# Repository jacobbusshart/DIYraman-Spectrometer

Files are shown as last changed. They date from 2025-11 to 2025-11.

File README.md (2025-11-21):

# DIYRaman – Open Hardware Raman Spectrometer 

An open, modular Raman spectrometer you can build, understand, and modify –  with documentation aimed at hobbyists, educators, and low-resource labs.

Full Assembly in Overpressure Glove Box without Cuvette

The goal is to make Raman spectroscopy **replicable, affordable, and well-documented**, so that motivated builders – including those without access to expensive equipment – can build a working system for:

- broad substance and drug identification *(qualitative, exploratory)*,
- basic materials identification,
- teaching optics and spectroscopy.

 Built from cost-efficient parts and repurposed components:
 
- a surplus spectrometer module [(B&W Tek - eBay](https://www.ebay.com/itm/143989529085)),
- a cheap 532nm laser pointer,
- 3D-printed parts,
- various used components.

For performance and reproducibility, essential optics had to be purchased new from Thorlabs and Edmund Optics – the most costly portion of this build:

- Dichroic Mirror (DMLP550 - Thorlabs, 230$)
- Longpass Filter (FELH0550 - Thorlabs, 170$)
- (Optional) Bandpass Filter (#65640 - Edmund Optics, 95$)

A detailed overview of all the used parts and cost can be found under `/bom/BOM (Bill of Materials).md`

This repository contains:

- **Build documentation** (step-by-step with images),
- **Hardware design files** (3D models and Fusion CAD files),
- **Software** for acquisition and visualisation,
- **BOMs** with parts, essential properties and alternatives.

> 💡 This README is a *project overview*. Detailed build instructions can be found in `docs/` and the dedicated pages (Basic Assembly, Glove Box, Linear Stage, Full Assembly, …).

---

## Who is this for?



DIYRaman is designed for:

- 🛠️ **Makers & hobbyists** with a 3D printer and basic electronics skills  
- 📚 **Teachers & students** who want a hands-on, explainable spectrometer  
- 🌍 **Low-resource labs** where commercial Raman devices are inaccessible  
- 💊 **Curious experimenters** exploring qualitative screening and comparison

You should be comfortable with:

- basic hand tools,
- 3d-printing,
- following technical step-by-step instructions,
- handling lasers safely - or receive guidance from someone.

> ⚠️ **Not a certified analytical instrument**  
> DIYRaman is a learning and research tool. It is **not validated** for clinical, regulatory, or forensic decisions and only yields broad qualitative results.

---

## What can it do?

The completed Raman build offers:

- **Stokes region** above ~600 cm⁻¹  
- solids / liquids in a cuvette-type sample holder  
- qualitative & educational use (comparison, teaching, demos)  
- extensible design (alternative spectrometers, lasers, mechanics)

> 🧪 **Drug / counterfeit screening**  
> The system can be used for *exploratory, educational* screening of unknowns (e.g. counterfeit pills) but **must not** be treated as a validated forensic tool. **Always cross-check with certified methods!**

---

## Project status

> **Early open release — Work in progress**

Hardware and docs are under active development. Conventions, part numbers, files, and instructions may change.

Current module status:

- ✅ **Basic Raman Optical Assembly** – documented and buildable  
- ✅ **Overpressure Glove Box** – documented and buildable  
- 🟡 **Linear Translation Stage** – documented, design still being adjusted  
- 🟡 **Spectrometer Unit** – usable, documentation in progress  
- 🟠 **Full Raman Optical Assembly** – documentation in progress  
- 🔴 **First Acquisition & Software / GUI** – unpublished  

Breaking changes may occur; expect adjustments until the first tagged release.

---

## Repository structure (WiP – early draft)

```text
assets/
  images_animated/
  images_infographic/
  images_picked/
  images_pictures/
  images_print-orientation/

bom/
  BOM.csv                 # Incomplete; updated in respective instruction!
  
docs/
  instructions/           # Step-by-step build docs

parts/                    # .STL-files for 3D-printing
  basic-assembly/
  glovebox/

results/                  # Captured example spectra

software/                 # Planned

LICENSES/
  CERN_OHL_S_V2.txt
  CC-BY-SA-4.0.txt
  MIT.txt
```

- Build *instructions* in `docs/instructions/`.  
- Hardware *source files* in `parts/`.
- All *images* and supporting graphics in `assets/`.
- Complete BOM in `bom/` and respective instruction.  
- License texts in `LICENSES/`.

---

## Build path (recommended)

A suggested build order for new users:

1. **Spectrometer Setup**  
   – Become comfortable with the operation of the spectrometer unit .  
2. **Overpressure Glove Box**  
   – Keep dust away from optics and make laser alignment safer.  
3. **Basic Raman Optical Assembly**  
   – Align the basic backscattering optical path.  
   - *Acquire your first rough spectrum.*  
3. **Linear Translation Stage**  
   – Add fine focus control for the focusing optics.  
4. **Full Raman Optical Assembly**  
   – Add motorisation, translation stage, and refinements.  
   - *Acquire your first usable Raman spectrum.*  
5. **Calibration** *(planned)*  
   – Calibrate wavelength axis and intensity where feasible.  
6. **Upgrade options** *(planned)*  
   – Alternative optics, higher-quality mechanics, software features.



---

## Contributing

Contributions are very welcome – especially from people building the system.

You can help by:

- reporting unclear or missing steps in the docs,  
- proposing improved or more accessible part choices,  
- designing mechanical variants (e.g. alternative mounts, stages),  
- improving the GUI / firmware,  
- sharing example spectra and calibration tips.

---

## Teaching & research use

If you use DIYRaman in teaching, workshops, or research:

- Consider contributing your **findings, documentation, worksheets, or demos** back to the project.  
- If you publish work based on DIYRaman, please cite it so others can find it.

Until the first proper release is published, you can use the following citation: 

> **DIYRaman - Open Hardware Raman Spectrometer (Github),**   
> *Jacob Busshart, DIYraman.com*

---

## Acknowledgements

This project builds on the shared knowledge and contributions of the open-hardware community. Some particularly helpful references and inspirations:

- [OpenRaman.org](https://www.open-raman.org/) & [ThePulsar.be](https://www.thepulsar.be/article/diy-raman-spectroscopy/) (Luc)  
- [PhysicsOpenLab.org – Backscattering Raman system](https://physicsopenlab.org/2022/04/22/backscattering-raman-system/)  
- [Laserpointerforums.com – B&W Tek spectrometer thread](https://laserpointerforums.com/threads/b-w-tech-spectrometer-473-module-setup-mods-info.101467/)

If you adapt or extend this design, please consider releasing your variant as open hardware too – especially if it makes the system easier to build in your local context.

---

## Licensing – open hardware setup

DIYRaman separates licenses for **hardware**, **documentation**, and **software**.  
This follows common open-hardware practice and simplifies reuse.

**Hardware**: 
All **hardware design files** in this repository (mechanical CAD, STLs, STEP files, electronics schematics and layouts) are licensed under:
**CERN-OHL-S v2**
`LICENSES/CERN_OHL_S_V2.txt` 

**Documentation**: 
All **build instructions, diagrams, and written documentation** in this repository are licensed under: 
**Creative Commons Attribution-ShareAlike 4.0 International (CC BY-SA 4.0)**
`LICENSES/CC-BY-SA-4.0.txt`

**Software**: 
All **software** in this repository (code and firmware) is licensed under:
**MIT License**
`LICENSES/MIT.txt`

---

*NOTE: Some parts of the written documentation has been formatted or translated using AI.*



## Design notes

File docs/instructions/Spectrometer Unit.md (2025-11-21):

# Spectrometer Unit (B&W Tek BTC-110S)

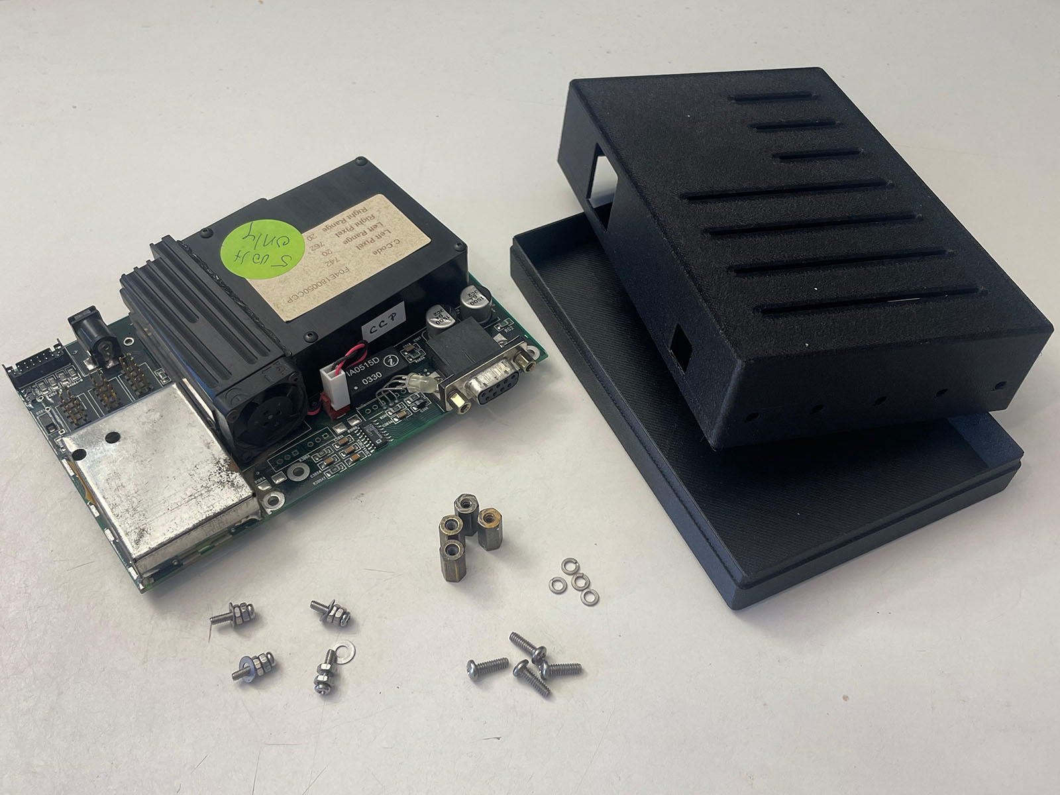
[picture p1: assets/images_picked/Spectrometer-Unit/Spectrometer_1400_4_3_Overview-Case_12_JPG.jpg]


This module describes how to prepare, house and use the [**B&W Tek BTC-110S**](https://www.ebay.com/itm/143989529085) spectrometer board as the detector for the DIYraman system.

It covers inspection and cleaning, the 3D-printed housing, first power-up, acquiring spectra, and basic wavelength calibration.

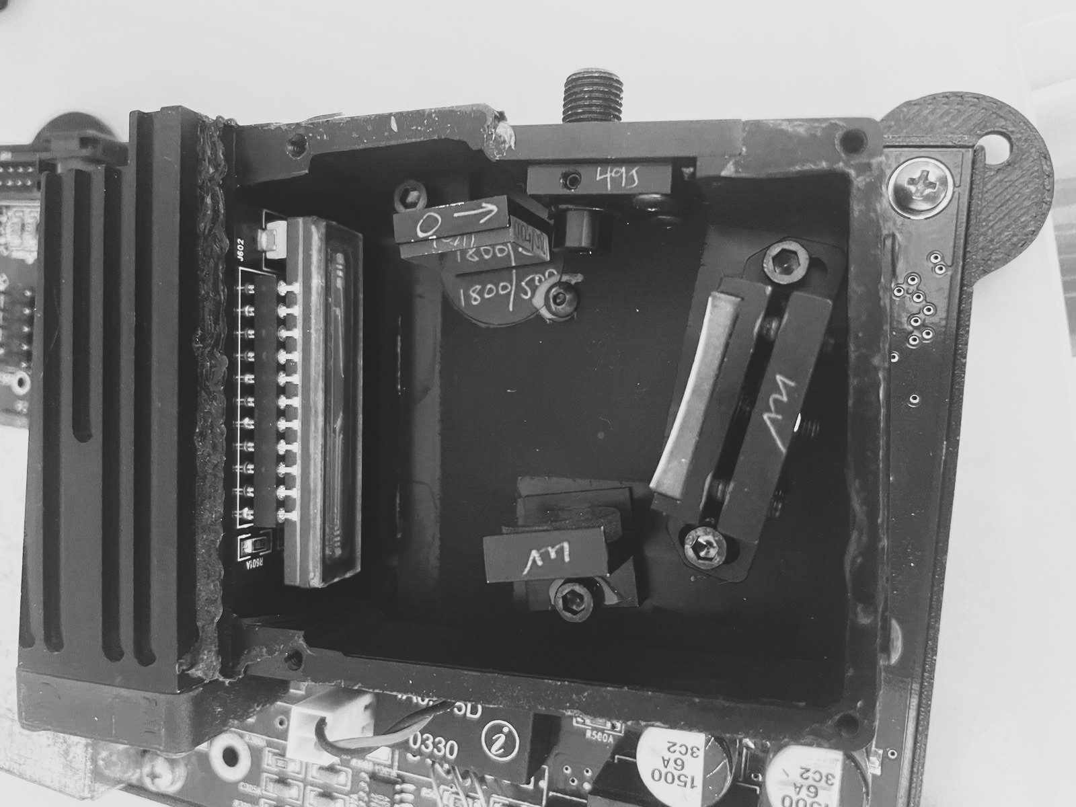
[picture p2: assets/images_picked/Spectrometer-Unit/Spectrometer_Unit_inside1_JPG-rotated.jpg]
View inside the optical assembly of the Spectrometer Unit BTC-110S


***For an in-depth look into the capabilities and operation of the unit, visit this blog post ["Home Optical Spectrometry: The B&W Tek BTC100-2S"](https://www.sevarg.net/2023/01/28/bw-tek-btc100-spectrometer/) on Sevarg.net!***

---

## Jump to

- [1. Parts and Tools](#1-parts-and-tools)
- [2. Inspect and Clean the Unit](#2-inspect-and-clean-the-unit)
- [3. 3D-Printed Housing](#3-3d-printed-housing)
- [4. Powering On and Connecting](#4-powering-on-and-connecting)
- [5. Acquiring a First Spectrum](#5-acquiring-a-first-spectrum)
- [6. Wavelength Calibration](#6-wavelength-calibration)
- [7. Upgrade Options (Optional)](#7-upgrade-options-optional)
- [Appendix – Background](#appendix--background)

---

## 1. Parts and Tools

### 1.1 Sourced parts

| Part | Minimum spec / example | Notes |
| --- | --- | --- |
| Spectrometer board | **B&W Tek BTC-110S** ([Available on eBay](https://www.ebay.com/itm/143989529085)) | Main detector module. |
| Power supply | 5 V, ≥ 3 A, barrel jack connector | Must be stable and regulated. |
| Data cable | RS-232 to USB adapter cable | Choose a chipset compatible with your OS (many FTDI / Prolific chips work reliably). |
| Calibration source | CFL or mercury-vapour / calibration lamp | Needs several sharp lines near ~550 nm for wavelength calibration. |

> [!TIP] Budget builds  
> Used BTC-110S boards are available on eBay but may also appear via surplus or auction sites and are much cheaper than new spectrometers or even buying the parts.

---

### 1.2 Tools

- Small **hand blower** (camera cleaning blower) or compressed inert gas  
- Lint-free cloth and **99 % isopropanol**  
- Cotton swabs  
- Basic screwdrivers and hex keys (for standoffs / case)  
- 3D printer capable of PETG or PETG-CF  
- PC or laptop with Windows and:
  - Original B&W Tek software (re-hosted)  
  - Optional: DIYraman acquisition software (see [Software – README](../../software/README.md))

---

## 2. Inspect and Clean the Unit

Before printing parts or powering anything, make sure your spectrometer arrived intact. 

### 2.1 Visual overview

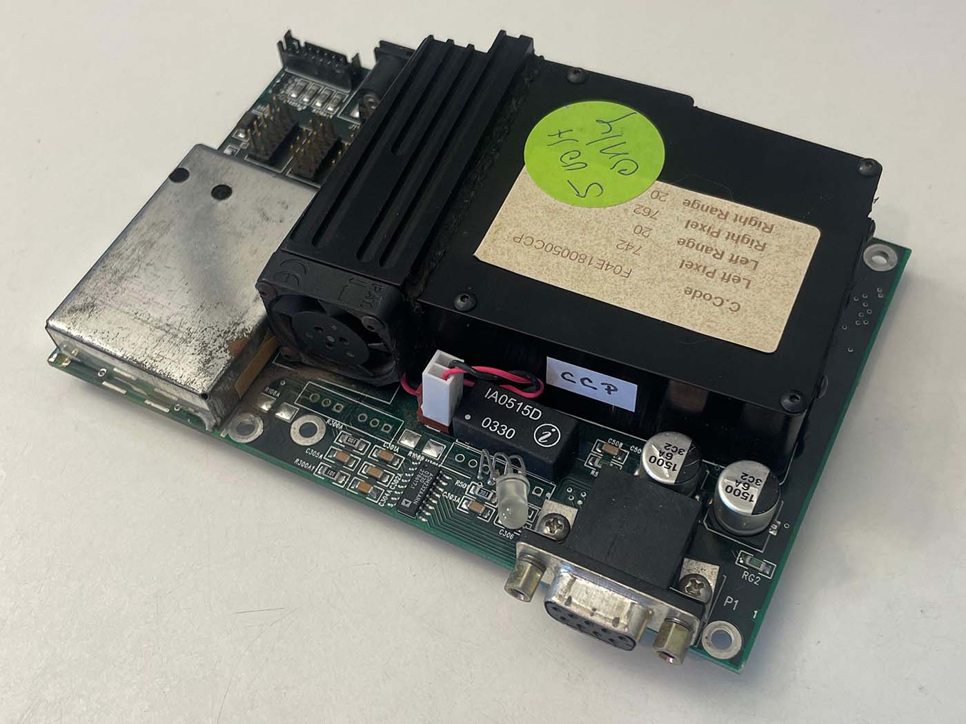
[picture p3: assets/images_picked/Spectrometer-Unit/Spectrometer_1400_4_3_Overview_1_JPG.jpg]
Spectrometer unit out of the box
  
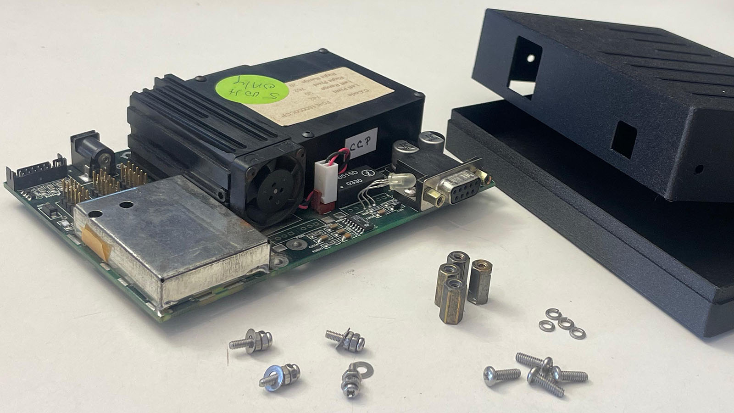
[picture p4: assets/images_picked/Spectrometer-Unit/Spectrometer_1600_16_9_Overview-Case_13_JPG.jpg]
Spectrometer with printed case, standoffs and screws

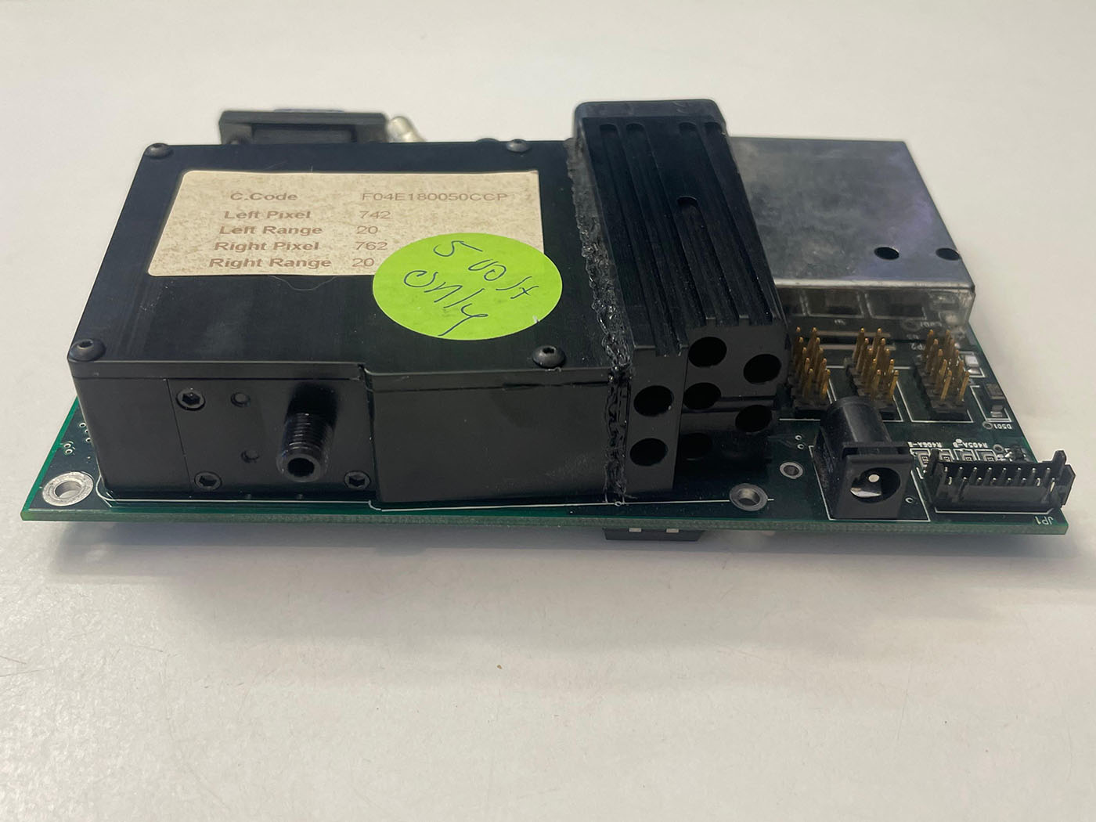
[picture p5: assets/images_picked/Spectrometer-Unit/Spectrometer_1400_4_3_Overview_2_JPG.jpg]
Spectrometer top-rear view with SMA905 input
  
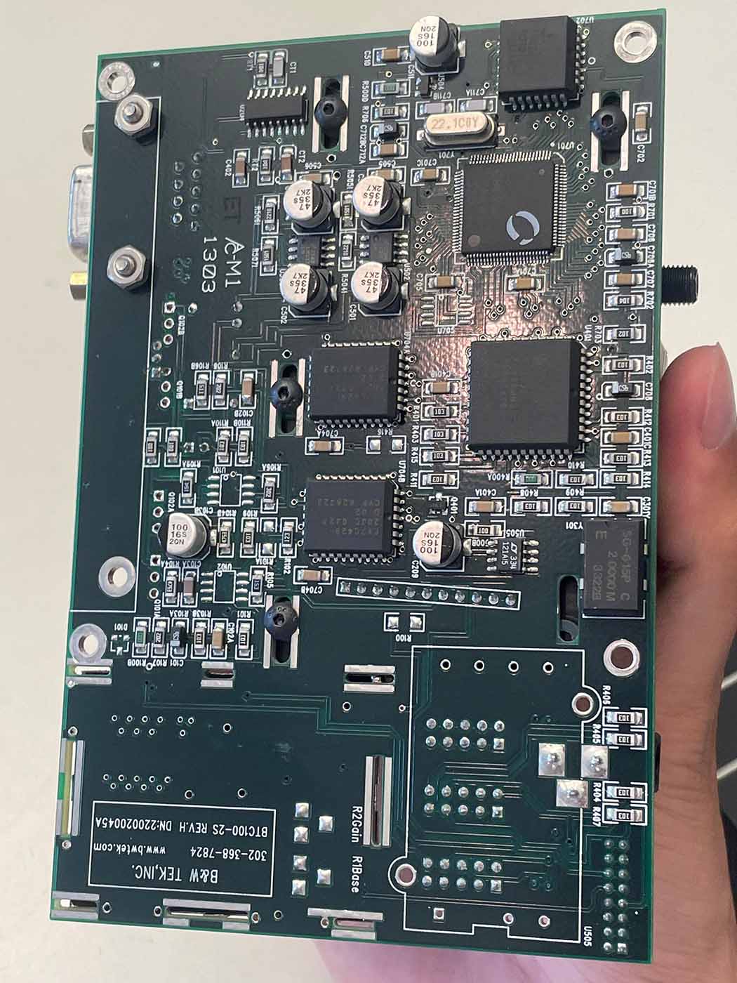
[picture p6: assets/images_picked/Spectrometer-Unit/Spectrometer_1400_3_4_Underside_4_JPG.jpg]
Underside of the PCB


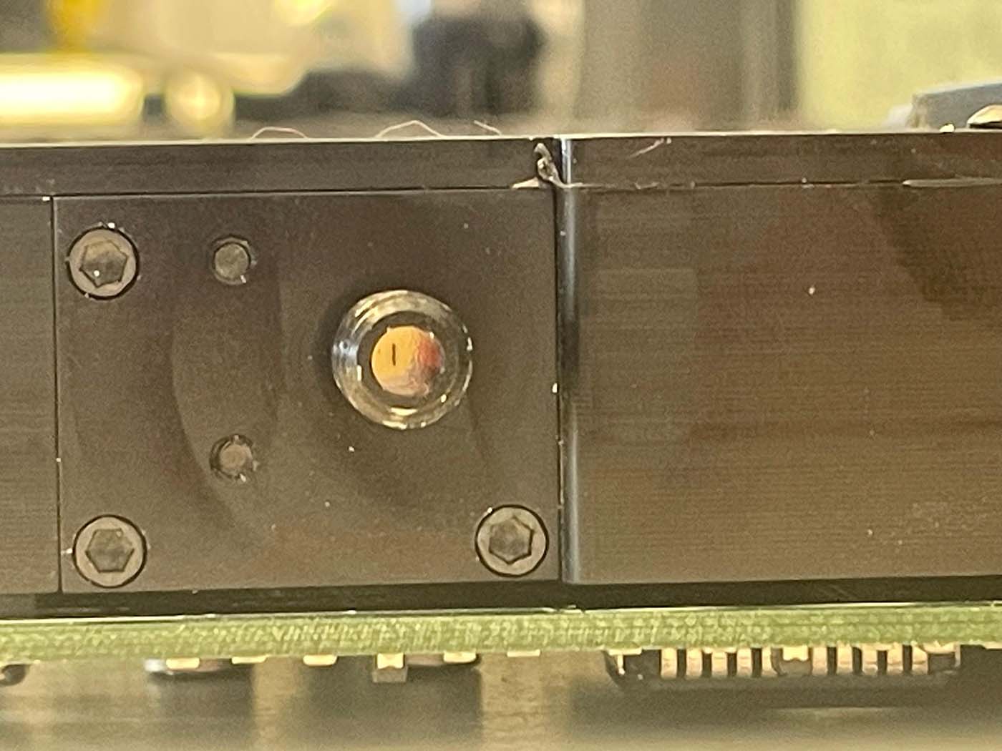
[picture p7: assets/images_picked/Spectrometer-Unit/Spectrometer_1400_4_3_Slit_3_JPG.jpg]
Close-up of the input with 50 µm slit


Check:

- PCB is not bent or cracked.  
- SMA905 input stud is straight and the glass slit is intact.  
- Heatsink, fan and connectors are firmly attached.

### 2.2 Cleaning

1. Use a blower or compressed gas to gently **dust off the PCB and the fan**.  
2. Lightly dampen a lint-free cloth with **99% isopropyl alcohol (IPA)**.  
3. Wipe non-optical surfaces: metal case, heatsink, backside of the PCB.  
4. Use cotton swabs with a small amount of isopropanol to clean tight areas.  
5. **Do not touch** the slit glass, sensor or any exposed optical surfaces directly. 

> [!WARNING] Health & safety – sanding fibre-filled plastics  
> When sanding or trimming 3D-printed parts made from PETG-CF or other fibre-filled filaments, wear at least a **surgical mask or FFP2/FFP3 respirator**. Fine carbon fibres can accumulate in your lungs with repeated exposure. 

---

## 3. 3D-Printed Housing

The BTC-110S is an exposed PCB assembly. A simple printed case protects it from dust, stray light and accidental damage.



### 3.1 Printed parts

| ID  | Name | Qty | Print notes |
| --- | --- | --- | --- |
| 201 | `Spectrometer-Case_Bottom.stl` | 1 | |
| 202 | `Spectrometer-Case_Top.stl` | 1 | |

#### Print orientation & fit

If parts / holes are too tight or too loose:

- **Too tight:** very lightly ream or sand the holes, then remove dust.  
- **Too loose:** adjust XY compensation / hole expansion in your slicer and reprint. 

> [!TIP] Print seams for precise holes  
> Avoid seam placement directly inside precise holes. Random seam positioning often yields better clearance for functional features.

---

## 4. Powering On and Connecting

This section gets the spectrometer powered and talking to your computer. 

**For an in-depth look into the capabilities and operation of the unit, visit this blog post ["Home Optical Spectrometry: The B&W Tek BTC100-2S"](https://www.sevarg.net/2023/01/28/bw-tek-btc100-spectrometer/) on Sevarg.net!**

### 4.1 Warm-up

1. Connect the **5 V / 3 A power supply** to the barrel jack.  
2. Plug it in – there is no power switch, so you immediately hear the small fan spin up.  
3. Leave the unit on for **≈ 10 minutes** before serious measurements.

The BTC-110S uses a **thermoelectric cooler (TEC)** plus heatsink and fan to stabilise the sensor temperature. Starting measurements immediately after power-on leads to higher background noise and random spikes until the temperature settles!

### 4.2 RS-232 to USB adapter

Connect the RS-232 adapter between the DB-9 port and your PC. 

> [!NOTE] USB–RS-232 compatibility  
> Some USB–RS-232 chipsets behave poorly on non-Windows systems or inside virtual machines. A mid-range cable from a known brand (e.g. Ugreen / FTDI-based) tends to work more reliably than ultra-cheap clones.

---

## 5. Acquiring a First Spectrum

For initial testing, use the **original B&W Tek software** ([Spectrum Studio - Click to Download](https://drive.google.com/file/d/1ooKja8GXg5gMX-swFjbmAXFP61ucyWT_/view?usp=sharing)) to confirm that communication and data acquisition work as expected.

### 5.1 Software setup

1. Start the OEM software with the spectrometer powered.  
2. If it doesn’t auto-detect the device:  
   - Click **“Detect Spectrometer”** in the toolbar.  
   - Wait for the blank graph to appear.  
3. Open the **“Calibrate”** window (gear icon at the right of the toolbar).  
4. Set parameter **C1 = 1** at the bottom and confirm with **OK** – this enables the wavelength calibration features you’ll need later.

### 5.2 Understanding integration time and averaging

- **Integration time** ≈ camera shutter speed.  
  - ~50 ms: quick checks and rough alignment.  
  - 1500–20000 ms: typical range for final Raman measurements.  
- **Averages**: number of individual spectra that will be acquired and averaged, even when you press **“Scan Once”**. During acquisition, the software shows the most recent scan, then updates to the averaged, background-subtracted spectrum at the end.

### 5.3 Capturing and subtracting background

1. Block the input slit (e.g. with your finger, a printed cap or tape).  
2. Start an acquisition with typical settings.  
3. Use the **green arrow icon** in the left toolbar (background submenu) to:  
   - Capture the current spectrum as **background**.  
   - Apply it to subsequent scans.

This background remains active and will be subtracted from all new spectra until you clear or update/replace it.

> [!WARNING] Re-acquire background after changing integration time  
> Whenever you change the **integration time**, capture a **new background**. The OEM software does not warn you or clear the old background automatically – it will otherwise subtract an incorrect background.

---

## 6. Wavelength Calibration

Proper wavelength calibration maps each CCD pixel index to a physical wavelength in nanometres. This step is essential for **correctly scaled Raman shifts**. 

### 6.1 Choose a calibration source

A good calibration source has:

- Several sharp, well-documented emission lines  
- Lines close to the region of interest (around 550 nm for a 532 nm Raman system)

Suitable options:

- Mercury-vapour lamp (ideal, easiest)  
- CFLs with visible mercury lines (abundant, low-cost)  
- Dedicated calibration lamps from astronomy suppliers (more expensive)

You can find reference spectra and line lists for mercury-vapour lamps in many spectroscopy references and online databases.

### 6.2 Record calibration data

1. **Acquire and apply a background** of the sensor noise.
	- If the spectrometer was just powered on, leave it running for roughly 10 minutes until the measured noise stabilizes.
2. Turn off all lights in the room to avoid stray lines. 
3. Place the calibration lamp so light enters the slit (directly or via SMA fibre, if used).  
4. Adjust integration time until you get:  
   - Clearly visible peaks  
   - No saturated pixels  

Now use the software’s **cursor tool** (two icons above background subtraction in the left toolbar):

5. Drag the vertical line to each prominent spectral peak.  
6. For each peak, note:
   - The **pixel index** (x-axis value before calibration)  
   - The **known wavelength** (from your reference data)

Collect at least **4 calibration points** across the usable range – more points give a better fit.

### 6.3 Least-squares fitting

1. Open the **Calibrate** window again.  
2. Switch to the **“Least-Squares Fitting”** tab.  
3. Enter all recorded **pixel indices** and **wavelengths** into the table.  
4. Let the software compute the calibration coefficients.  
5. Write these values down or take a screenshot for future reference.  
6. Confirm with **OK**, then take another scan.

The x-axis should now be displayed directly in **nanometres** instead of raw pixel numbers.

### 6.4 Quick sanity check

> [!DANGER] Laser safety  
> Never look directly into the beam or reflections, and be especially careful with cheap DPSS lasers that may leak significant invisible infrared!  

1. Gently shine a **green 532 nm laser** at the entrance slit.  
   - Avoid over-exposing the sensor; use reflections or a diffuser if needed.  
2. Acquire a spectrum and check the main laser line:  
   - Expect a peak somewhere around **528–536 nm**, depending on laser quality and calibration accuracy.  
3. If the peak is significantly off, re-check your calibration points. 

---

## 7. Upgrade Options (Optional)

These upgrades are **not required** to get a working Raman spectrometer, but can improve performance once the basic system runs reliably.

### 7.1 SMA905 fibre input

- The BTC-110S was designed to accept light via an **SMA905 fibre** threaded onto the entrance stud.  
- For many basic experiments and even Raman work, you can feed light directly into the slit without a fibre.  
- Fibre coupling is useful to:
  - Position the spectrometer unit outside of the [Overpressure Glove Box](Overpressure%20Glove%20Box.md).  
  - Route the signal over a longer distance.  
  - Re-use an existing fibre probe.

### 7.2 Protective slit cap

To protect the fragile 50 µm glass slit, you can add a simple screw-on cap:

- Download the provided **spectrometer screw cap** 3D model.  
- Print in black (or dark) filament:  
  - ≤ 0.2 mm layer height  
  - Random seam position  
- If the thread fit is off: scale the model slightly in XYZ (uniformly) and re-print.

### 7.3 Internal optics and grating

Many forum posts suggest tweaking mirrors or replacing the diffraction grating to increase resolution near the Raman region. While possible, this has trade-offs:

- Any misalignment can **ruin the instrument alignment** until fixed.  
- Adjustments need to be done:
  - In a **glove box** or dark enclosure  
  - With great patience and very small iterative changes

> [!TIP] Leave internal optics untouched (at first)  
> Leave the internal optics **as-is** until your full Raman system works and you have experience aligning external optics. Out-of-the-box performance of typical BTC-110S units is usually sufficient for 532 nm Raman in the 600–1650 cm⁻¹ region. 

---

## Appendix – Background

### A.1 Where the BTC-110S comes from

The BTC-110S was originally used inside the *Carotenoid Antioxidant Scanner* (NuSkin Pharmanex S3 BioPhotonic Scanner), a device marketed by a large MLM company. While the surrounding product and claims were questionable, the embedded spectrometer appears to be a legitimate and capable module – and is now available online.

### A.2 Spectrometer role in DIYraman

In the DIYraman system, the BTC-110S:

- Receives filtered Raman-scattered light from the optical assembly  
- Disperses it via an internal grating onto a linear CCD array  
- Outputs digitised intensity vs. pixel index, which is converted into:  
  - **Wavelength (nm)** after calibration  
  - **Raman shift (cm⁻¹)** in later software steps  

Its specified range is roughly **400–725 nm**, originally optimised for 400–580 nm, but still well suited for the **Stokes region** above a 532 nm excitation, even with a 550 nm long-pass filter. In practice, most useful Raman bands (≈450–1650 cm⁻¹) fall within the captured region, even if the very lowest shifts below ~600 cm⁻¹ are clipped.

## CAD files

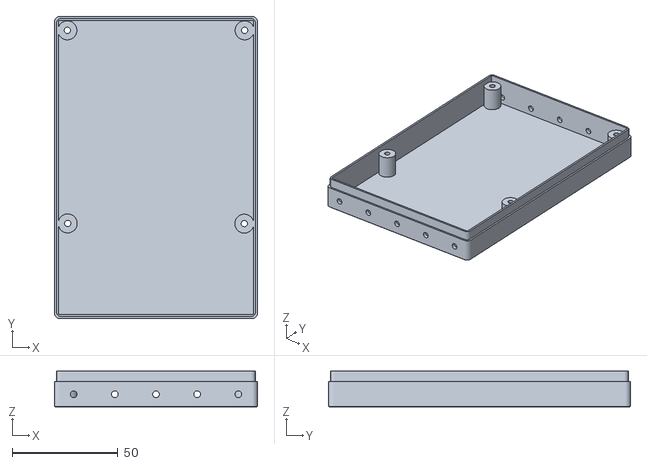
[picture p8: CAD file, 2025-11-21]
parts/spectrometer-unit/Spectrometer-Case_Bottom.stl
96.2 x 143.2 x 17.0

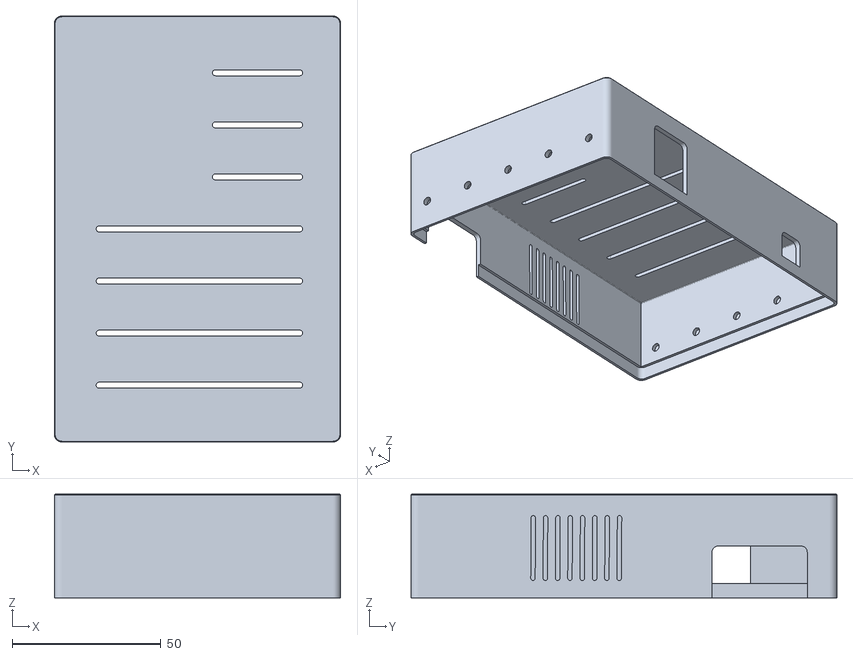
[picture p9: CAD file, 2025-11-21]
parts/spectrometer-unit/Spectrometer-Case_Top.stl
96.2 x 143.2 x 34.9

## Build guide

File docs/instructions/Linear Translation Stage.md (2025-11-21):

# Linear Translation Stage

Linear translation stage – assembled

%% Alle gedruckten Teile des Modells revisen, vor allem die Rods zu fixieren und Teile zu minimieren + dimensional accuracy der rod holes zu gewährleisten. 
+ überall noch step by step mittels DXF in Illustrator, analog zu Basic Assembly %%

Build a compact linear translation stage for fine axial adjustment of the focusing optics in the [Full Raman Optical Assembly](Full%20Raman%20Optical%20Assembly.md).

This stage uses:

- Two smooth metal rods as linear guides  
- A micrometer screw for precise movement  
- Two compression springs to pre-load the moving stage  

The design is simple to print and tune, and accurate enough to focus the final lens or fibre position onto the spectrometer input.

> [!NOTE] Where this stage is used  
> In the recommended build path, this translation stage sits underneath the **Focusing Assembly** [Focusing Assembly](Basic%20Raman%20Optical%20Assembly.md#Focusing%20Assembly) in the [Full Raman Optical Assembly](Full%20Raman%20Optical%20Assembly.md).  
> It is **not** required for the [Basic Raman Optical Assembly](Basic%20Raman%20Optical%20Assembly.md) but strongly recommended for comfortable fine focus adjustment.

---

## Parts and Materials

### Sourced parts

| Part | Qty | Specification / notes |
| --- | --- | --- |
| Micrometer screw | 1×  | ~10–15 mm travel, with mounting nut/collar |
| Metal rods, ⌀ 6 mm | 2×  | ≥ 55 mm length, straight, smooth surface |
| Compression springs, ⌀ ≥ 6 mm | 2×  | Inner diameter slightly larger than 6 mm; stiffness chosen for light pre-load |
| M3.5 screw + washer + nut | 4×  | ≥ 20 mm length (for mounting the stage to the main baseplate or frame) |
| Sandpaper | – | ~150–240 grit for fine tuning of rod holes |
| (Optional) Lubricant | – | Light machine oil or PTFE/silicone-based lubricant for rods and sliding interfaces |

> [!NOTE] Micrometer choice  
> Any mechanical micrometer head with ~10–15 mm travel is suitable. The exact scale, brand and knob style are not critical as long as the body fits the printed holder.

---

### 3D-printed parts

> [!NOTE] STL files  
> All STL files are provided in the project repository. The BOM IDs below are used consistently across the documentation.

| BOM-ID | Part name (.stl) | Qty | Recommended print orientation | Notes | Preview |
| --- | --- | --- | --- | --- | --- |
| 011 | `LinearStage_Base_STL` | 1×  | Hole grid facing the build plate | Rod holes oversized (~⌀ 6.65 mm) to compensate vertical printing | LinearStage_Base |
| 012 | `LinearStage_Stage_STL` | 1×  | Rod holes facing the build plate | Rod holes sized (~⌀ 6.2 mm) for a snug but movable fit | LinearStage_Stage |
| 013 | `LinearStage_Frontplate_STL`  | 1×  | Flat face down, holes facing up | Optional stiffening / front support plate (recommended) | LinearStage_Frontplate |

> [!TIP] Suggested print settings  
> - Material: PETG-CF or regular PETG for stiffness and wear resistance  
> - Layer height: 0.2 mm  
> - Perimeters: ≥ 3 walls  
> - Infill: 30–40 % grid or gyroid  
> - Supports: Not required in the recommended orientations

---

## Preparing the Printed Parts

Good rod fit is critical for smooth and repeatable motion. Before full assembly, verify and tune the fit of the rods in both the base and the moving stage.

### Step 1 – Base (BOM 011, rod fit)

For the base, the rods should press in firmly and not move once installed.

1. Measure the rod diameter with digital callipers to confirm ~⌀ 6.0 mm.  
2. Push each rod all the way through the rod holes in `LinearStage_Base_STL`:

   Checking rod fit in the base

   - You should feel noticeable, even resistance as the rod enters the holes.  
   - Once inserted, the rods should not wobble or rattle in the base.

3. If the rods **do not fit at all**:  
   - Lightly sand the inside of the rod holes with rolled-up sandpaper.  
   - Clean the dust and test the fit again. Repeat until the rod can be pressed through with firm pressure.

> [!WARNING] Sanding fibre-reinforced filaments  
> When sanding PETG-CF or similar materials, wear appropriate PPE (at least a particle mask). Fine fibres and plastic dust can be harmful if inhaled, especially with repeated exposure.

4. If the rods have **visible play**:  
   - First confirm that the rods are actually ⌀ 6.0 mm (cheap rods can vary).  
   - If rods are correct, consider slightly shrinking the holes in your CAD/source file or using slicer hole compensation to reduce the effective hole size, then re-print the base.

> [!TIP] Print seam settings  
> If your slicer allows it, use **random seam positioning** for this part. This avoids a single pronounced seam ridge inside the hole that can interfere with accurate rod fit.

---

### Step 2 – Stage (BOM 012, sliding fit)

The stage must slide smoothly on the rods with minimal play.

1. Insert a rod into one of the holes in `LinearStage_Stage_STL` and push it through:

   Checking rod fit in the stage

   - The rod should move with slight resistance but **not** bind or jam.  
   - A small amount of stiffness is acceptable and often improves after some movement or light lubrication.

2. Repeat for the second rod hole. Both rods should slide similarly.

3. If the fit is **too tight or jerky**:  
   - Very lightly sand the inside of the rod holes.  
   - Clean the dust and test again.

4. If the fit is **very loose** and the stage can tilt on the rods, consider:  
   - Reducing the hole size in the source file or with slicer hole compensation, then re-printing, or  

> [!INFO] Clean after sanding  
> After sanding, remove dust with compressed air or a vacuum and wipe the parts with a damp paper towel. Loose particles can increase friction and wear over time.

---

## Assembly

Exploded view and motion of the linear stage

Once the printed parts are tuned for proper rod fit, you can assemble the stage.

### Step 3 – Install the micrometer screw

1. Insert the **micrometer head** into the central opening of `LinearStage_Base_STL` from the front.  
2. Use the nut supplied with the micrometer to secure it against the base.  
3. Make sure that:  
   - The micrometer axis is aligned with the central recess in the `LinearStage_Stage_STL`. 
   - The micrometer body does not collide with the rods or springs over the full range of motion.

> [!TIP] Avoid overtightening the micrometer nut  
> Tighten only until the micrometer body does not move when you try to rotate or pull it by hand. Over-tightening can warp the printed base or damage the micrometer threads.

---

### Step 4 – Install rods and stage

Assembly animation – base, rods, stage, springs

1. Insert both ⌀ 6 mm rods from the **same side** of the `LinearStage_Base_STL`. Push them approximately **one third** of the way in.  
2. Position the `LinearStage_Stage_STL` so that its central recess faces the **tip of the micrometer screw**.  
3. Carefully align the two rod holes in the stage with the rods and slide the stage onto the rods.  
4. Make sure the micrometer tip sits in the central recess of the stage or contacts the intended push surface.  
5. Push the rods further through the base and stage until they protrude slightly on the opposite side, leaving room for the springs.

> [!WARNING] Do not force misaligned rods  
> If the rods do not slide through the stage easily, remove the stage and check alignment. Forcing misaligned rods can crack the printed part or bend the rods.

---

### Step 5 – Add the springs

1. Slide one compression spring onto each rod.  
   - It is often easiest to place the spring on the rod first and then compress it into the recess between base and stage.  
2. Seat each spring so it sits **between the base and the stage** in the intended recess, providing a light pushing force against the stage.  
3. Push the rods fully into the base until:  
   - The springs are slightly pre-loaded (compressed a few millimetres), and  
   - The rods are fully seated in both ends of the base.

4. Gently turn the micrometer screw to move the stage through its travel:  
   - The stage should move smoothly with no sudden jumps.  
   - There should be minimal backlash (lost motion) when reversing direction.  
   - The springs should stay seated and not buckle.

5. Apply a **small amount of lubricant** to the rods if needed to improve the feel of the motion.

---

### Step 6 – Optional: Front plate (BOM 013)
%% Frontplate anders implementieren, wobei print orientation hier schon essenziell ist, wenn die Stage vertikal gedruckt wird - vor allem für die Rod holes. Eventuell die Base anders gestalten, um beide Seiten flush aber in richtiger Orientierung geprinted zu haben %%
1. Align `LinearStage_Frontplate_STL` with the corresponding holes on the front of the `LinearStage_Base_STL`.  
2. Fix the front plate with four suitable screws (e.g. M3.5 with washers and nuts), tightening evenly.  
3. Verify that:  
   - The rods remain parallel and properly seated.  
   - The stage still moves freely over the desired range.  
   - The micrometer tip remains correctly engaged with the stage.

The front plate increases stiffness at the front end of the rods and reduces the risk of flex when the stage changes direction.

---

## Mounting to the Raman Baseplate

In the **Full Raman Optical Assembly**, this stage is mounted beneath the focusing optics module.

1. Identify the mounting pattern for the translation stage on your Raman baseplate (see [Full Raman Optical Assembly](Full%20Raman%20Optical%20Assembly.md)).  
2. Disassemble the desired `Defaultholder` that holds the focusing lens by sliding it off the assembly rods.
3. Use four screws to mount the optic holder to the stage.
4. Place the assembled linear translation stage on the baseplate and align the mounting holes.  
5. Use four screws and nuts to fasten the stage - using an L-bracket - to the baseplate.  
6. Tighten all screws evenly, then verify that the stage still moves smoothly, no screw heads interfere, and that the micrometer remains accessible from the desired side.

> [!NOTE] Orientation on the baseplate  
> Mount the stage so that the micrometer is accessible from the front or side you find most convenient when adjusting. The exact orientation is not critical as long as the axis of motion aligns with the optical axis of the focusing optics.

---

## Design Notes and Tuning

For this design, part of the micrometer’s total travel is intentionally used to:

- Pre-load the springs (so the stage is always pressed firmly against the micrometer tip), and  
- Avoid fully compressing the springs at the end of travel (to keep motion smooth and predictable).

In practice, the **useful travel** of the stage is around **5 mm**, which is more than sufficient for fine focus adjustment of the final lens (or fibre input) in the [Full Raman Optical Assembly](Full%20Raman%20Optical%20Assembly.md).

The spring pre-load:

- Reduces backlash when reversing micrometer direction  
- Keeps the stage under constant tension  
- Improves repeatability of small position changes

> [!NOTE] Tuning the feel  
> You may need to experiment with different springs and pre-load amounts.  
> - Too little tension → noticeable backlash and vague response when reversing.  
> - Too much tension → high torque required on the micrometer, especially near travel limits.  
> Aim for a point where the stage moves smoothly and repeatably with moderate turning force.

---

## Related

- [Build an Overpressure Glove Box](Overpressure%20Glove%20Box.md)  
- [Basic Raman Optical Assembly](Basic%20Raman%20Optical%20Assembly.md)  
- [Full Raman Optical Assembly](Full%20Raman%20Optical%20Assembly.md)
